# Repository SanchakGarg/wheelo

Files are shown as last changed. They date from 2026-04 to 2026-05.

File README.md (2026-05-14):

# Wheelo: Scissored CMG Balancing Robot

Wheelo is an open-source, single-axis balancing robot that uses a **Scissored Control Moment Gyroscope (CMG)** system for stabilization. Unlike traditional balancing robots that use wheel acceleration, Wheelo stays upright by harnessing gyroscopic precession torque.

## Videos

| Demo | Working Principle |
|---|---|
| Wheelo Demo (https://www.youtube.com/watch?v=aaRE76FrkvM) | Wheelo Working (https://www.youtube.com/watch?v=aowIbTuXIWc) |

## Key Features

- **Scissored CMG Design:** Two counter-rotating flywheels geared together to provide pure torque and cancel parasitic yaw/roll.
- **XIAO ESP32-C3 Core:** Compact, powerful microcontroller with WiFi/OTA capabilities.
- **High-Speed Actuation:** ST3215 1 Mbps Serial Bus Servo for precise gimbal control.
- **Advanced Filtering:** Mahony filter with Median and Low-Pass stages for stable orientation sensing.
- **Web Dashboard:** Real-time PID tuning, telemetry, and calibration via a built-in web server.
- **OTA Updates:** Flash new firmware over WiFi — no USB cable needed after first flash.

## Repository Structure

```
Wheelo/
├── firmware/main/          # PlatformIO ESP32-C3 project
│   ├── platformio.ini      # Build environments (usb + ota)
│   └── src/
│       ├── config.h        # All pin assignments and tunable constants
│       ├── main.cpp        # Entry point — wires up modules, runs 10 ms PID loop
│       ├── BalancePID.cpp/h     # XRobots-V2 style angle PID with setpoint accumulator
│       ├── MPUSensor.cpp/h     # MPU6050/6500 driver + Mahony filter
│       ├── ServoController.cpp/h  # ST3215 half-duplex UART servo
│       ├── ESCController.cpp/h # BLDC ESC PWM driver (capped at 30%)
│       └── WebUI.cpp/h         # HTTP server — dashboard, PID tuning, telemetry
├── hardware/
│   └── Gyroscope Assembly.3mf  # 3D print files (Bambu/PrusaSlicer)
├── tools/
│   ├── sim_filter.py       # Off-robot Mahony filter simulation against recorded data
│   └── telemetry.py        # Real-time WiFi telemetry logger
└── docs/
    └── sim_filter_results.png  # Filter validation output
```

## Hardware

### Components

| Role | Part |
|---|---|
| MCU | Seeed Studio XIAO ESP32-C3 |
| IMU | MPU6050 / MPU6500 |
| Gimbal Servo | Waveshare ST3215 (Serial Bus Servo, 1 Mbps) |
| Flywheel Motor | BLDC Motor + ESC (2S–3S LiPo) |

### Pin Map

| Signal | GPIO | Board Label |
|---|---|---|
| ESC PWM | 10 | D10 |
| Servo TX | 20 | D7 |
| Servo RX | 21 | D6 |
| MPU SDA | 6 | D4 |
| MPU SCL | 7 | D5 |

### CAD

The mechanical design is available on Onshape: **[Wheelo CAD](https://cad.onshape.com/documents/1c7d4ff26d1dc69175c3ae98/w/5cd2b66e5aeb4751e0f29f10/e/76622d04818cc6738350398c)**

## Firmware Architecture

The firmware is split into six modules, each a self-contained C++ class:

| Module | File | Responsibility |
|---|---|---|
| **BalancePID** | `BalancePID.cpp` | XRobots-V2 direct-position PID. Outputs gimbal position commands. Includes setpoint accumulator to absorb chassis lean bias and prevent gimbal saturation. |
| **MPUSensor** | `MPUSensor.cpp` | Reads MPU6050/6500 over I2C. Applies a Mahony complementary filter plus median and low-pass stages. Exposes `pitch` and `gyroY` in degrees. |
| **ServoController** | `ServoController.cpp` | Drives the ST3215 over half-duplex UART at 1 Mbps. Reads back live gimbal position every 50 ms for closed-loop velocity computation. |
| **ESCController** | `ESCController.cpp` | Generates standard 1000–2000 µs PWM for the BLDC ESC. Throttle is capped at 30% for safety. |
| **WebUI** | `WebUI.cpp` | Serves a single-page dashboard on port 80. Endpoints for PID gains, servo manual control, IMU calibration, balance start/stop, and live telemetry. |
| **main** | `main.cpp` | Wires modules together, connects to WiFi, starts OTA, and runs a 10 ms PID tick in `loop()`. |

### PID Loop

The balance loop runs at **100 Hz** (every 10 ms). Each tick:
1. `mpu.read()` — fetches and filters a new IMU sample.
2. `pid.compute()` — runs the PID, moves the gimbal via `servo`.
3. `servo.readPos()` — runs at 50 ms cadence, keeps the position feedback fresh.

### Setpoint Accumulator

The setpoint accumulator (`accumEnabled`) slowly drifts the balance target toward the chassis's natural lean angle. This prevents the gimbal from parking at the edge of its travel and saturating on any second disturbance.

## Firmware Setup

### Prerequisites

- [PlatformIO Core](https://platformio.org/) (CLI or VS Code extension)
- Python 3.x (for `tools/`)

### Configuration

Edit `firmware/main/src/config.h` before building:

```cpp
#define WIFI_SSID     "YourNetwork"
#define WIFI_PASS     "YourPassword"
#define OTA_PASSWORD  "wheelo123"   // change for production
```

### Build & Flash

**First flash (USB):**
```bash
cd firmware/main
pio run -e usb -t upload
```

**Subsequent flashes (OTA — robot must be on WiFi):**
```bash
pio run -e ota -t upload
```

Serial monitor at 115 200 baud:
```bash
pio device monitor
```

## Web Dashboard

Once connected to WiFi, the robot advertises itself as `wheelo.local`. Open `http://wheelo.local` in a browser.

Available controls:
- **PID gains** (Kp / Ki / Kd / Trim) — live update with save to NVS
- **Setpoint Accumulator** toggle
- **Servo manual position** control
- **IMU calibration** (zero gyro bias, noise floor measurement)
- **Balance start / stop**
- **Live telemetry** (angle, gimbal position, PID output)

## Tools

| Script | Usage |
|---|---|
| `tools/sim_filter.py` | Replay recorded IMU CSV through the Mahony filter off-robot to validate tuning. |
| `tools/telemetry.py` | Connect over WiFi and stream live telemetry to a CSV for post-analysis. |

## License

This project is open-source under the MIT License. Feel free to build, modify, and share!

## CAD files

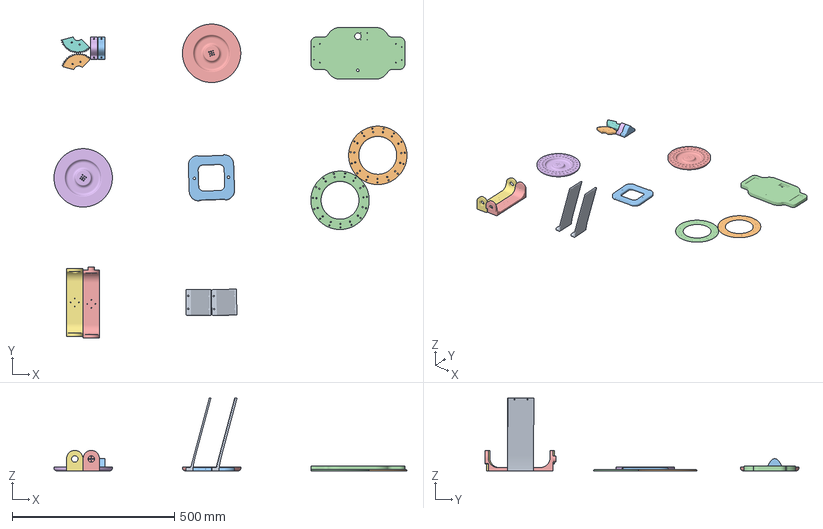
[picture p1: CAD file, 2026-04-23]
hardware/Gyroscope Assembly.3mf
1088.4 x 967.5 x 224.0 mm
Gyro - Support x 2
FlyWheel - cover x 2
Balance - Point x 2
Fly Wheel Stator - Mount x 2
Spur Gear x 2
Gyro - Top Joint
Gyro - Base
Fly Wheel - Base x 2

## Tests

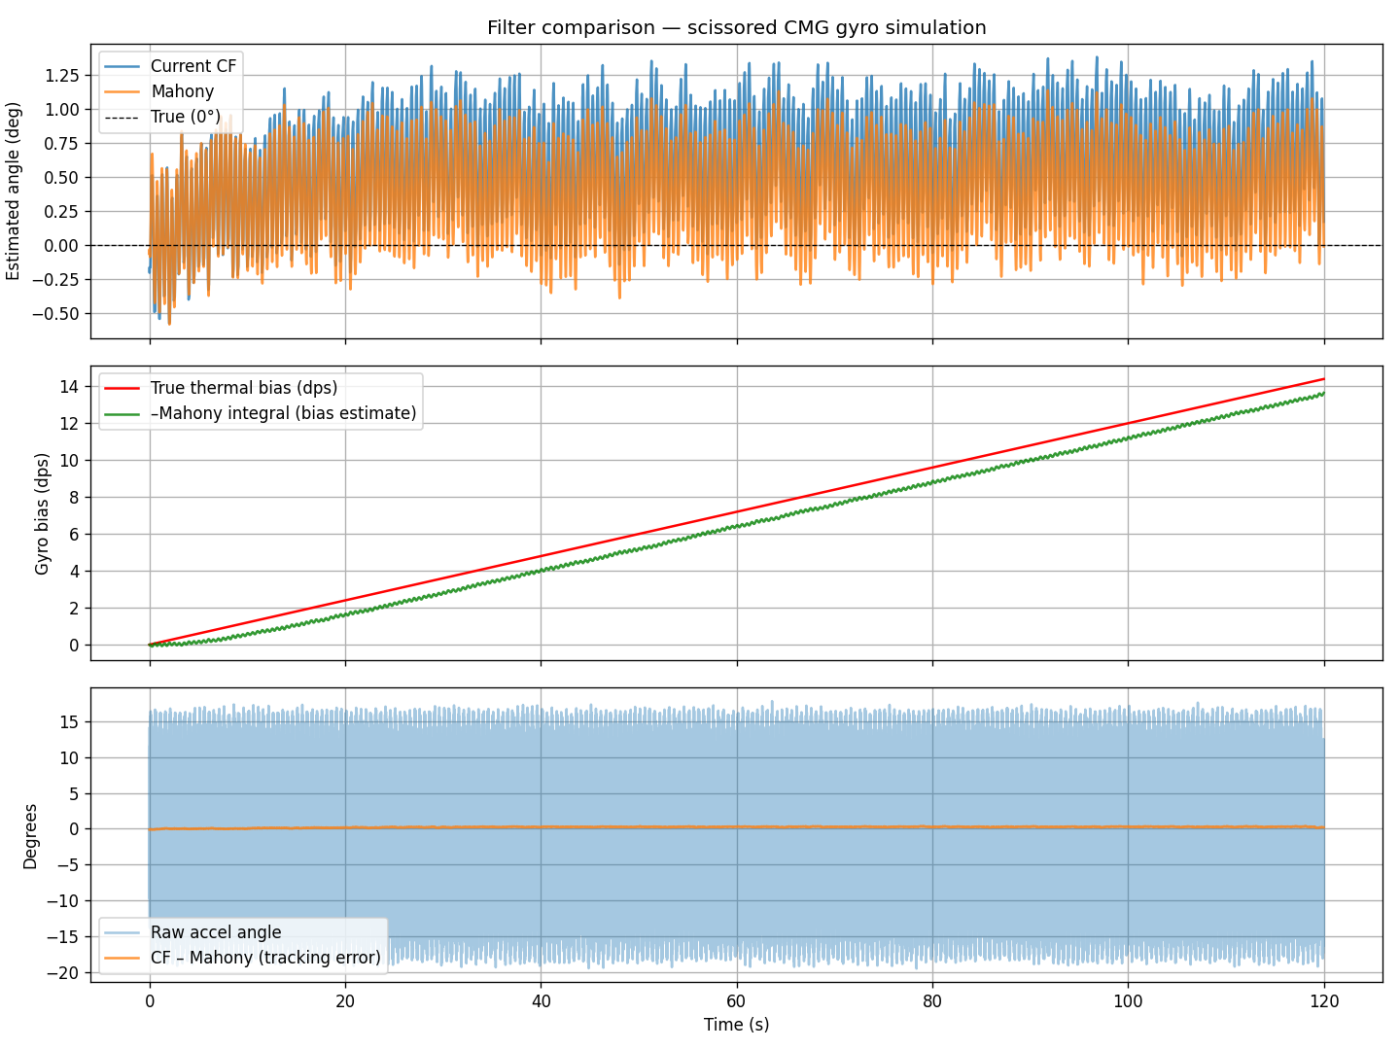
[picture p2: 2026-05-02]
docs/sim_filter_results.png

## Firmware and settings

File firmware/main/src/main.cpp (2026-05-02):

#include <Arduino.h>
#include <WiFi.h>
#include <WebServer.h>
#include <Preferences.h>
#include <ArduinoOTA.h>
#include "config.h"
#include "ESCController.h"
#include "ServoController.h"
#include "MPUSensor.h"
#include "BalancePID.h"
#include "WebUI.h"

Preferences     prefs;
WebServer       server(80);
ESCController   esc(PIN_ESC, ESC_MIN_US, ESC_MAX_US, ESC_MAX_PCT);
ServoController servo(SERVO_ID, BAUD_SERVO, PIN_SRV_RX, PIN_SRV_TX, SERVO_DEF, SERVO_SWING);
MPUSensor       mpu(MPU_ADDR, PIN_MPU_SDA, PIN_MPU_SCL);
BalancePID      pid(servo, mpu);
WebUI           ui(server, servo, esc, mpu, pid, prefs);

void setup() {
    Serial.begin(115200);
    delay(200);

    esc.begin();
    Serial.println("ESC armed at 0%");

    servo.begin(prefs);

    mpu.begin(prefs);
    pid.loadGains(prefs);

    WiFi.mode(WIFI_STA);
    WiFi.setSleep(false);
    WiFi.begin(WIFI_SSID, WIFI_PASS);
    Serial.print("WiFi");
    unsigned long t0 = millis();
    while (WiFi.status() != WL_CONNECTED && millis() - t0 < 30000) {
        delay(300);
        Serial.print('.');
        esc.setThrottle(0);
    }
    if (WiFi.status() == WL_CONNECTED)
        Serial.printf("\nIP: %s\n", WiFi.localIP().toString().c_str());
    else
        Serial.println("\nWiFi failed.");

    ui.begin();
    Serial.println("HTTP server started.");

    // OTA
    ArduinoOTA.setHostname(OTA_HOSTNAME);
    ArduinoOTA.setPassword(OTA_PASSWORD);
    ArduinoOTA.onStart([](){ Serial.println("OTA start"); });
    ArduinoOTA.onEnd([](){ Serial.println("\nOTA done"); });
    ArduinoOTA.onProgress([](unsigned int prog, unsigned int total){
        Serial.printf("OTA: %u%%\r", prog * 100 / total);
    });
    ArduinoOTA.onError([](ota_error_t err){
        Serial.printf("OTA error[%u]\n", err);
    });
    ArduinoOTA.begin();
    Serial.printf("OTA ready — hostname: %s\n", OTA_HOSTNAME);
}

void loop() {
    ArduinoOTA.handle();
    ui.handle();

    static uint32_t lastLoop = 0;
    static uint32_t lastReadPos = 0;
    uint32_t now = millis();

    // 10ms PID tick
    if (now - lastLoop >= 10) {
        if (mpu.read()) { pid.compute(); }
        lastLoop = now;
    }

    // 50ms servo position read. Runs during balancing too — compute() uses
    // currentPos as its velocity base, so it must stay fresh. readPos has a
    // 3ms timeout, so at worst one in five 10ms PID ticks is 3ms late.
    if (now - lastReadPos >= 50) {
        servo.readPos();
        lastReadPos = now;
    }
}

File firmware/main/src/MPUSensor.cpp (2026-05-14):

#include "MPUSensor.h"
#include "config.h"
#include <math.h>

MPUSensor::MPUSensor(uint8_t addr, int sda, int scl)
    : _addr(addr), _sda(sda), _scl(scl) {}

// 2nd-order Butterworth Low-Pass Biquad. 
// Sharp -40dB/decade roll-off to kill scissored-CMG vibration.
static float biquadLP(float x, float cutoffHz, float dt, MPUSensor::BiquadState &s) {
    float wc = 2.0f * 3.14159265f * cutoffHz;
    float k = wc * dt / 2.0f;
    float k2 = k * k;
    float sqrt2 = 1.41421356f;
    float norm = 1.0f / (1.0f + sqrt2 * k + k2);
    
    float b0 = k2 * norm;
    float b1 = 2.0f * b0;
    float b2 = b0;
    float a1 = 2.0f * (k2 - 1.0f) * norm;
    float a2 = (1.0f - sqrt2 * k + k2) * norm;

    float y = b0*x + b1*s.x1 + b2*s.x2 - a1*s.y1 - a2*s.y2;
    s.x2 = s.x1; s.x1 = x;
    s.y2 = s.y1; s.y1 = y;
    return y;
}

static float lowPass(float prev, float x, float cutoffHz, float dt) {
    const float rc = 1.0f / (2.0f * 3.1415926535f * cutoffHz);
    const float alpha = constrain(dt / (rc + dt), 0.0f, 1.0f);
    return prev + alpha * (x - prev);
}

// 5-element sorting network → median. Branch-only, ~9 compares, no allocs.
// Median rejects the impulse spikes BLDC commutation injects into the gyro
// without introducing the phase lag of an equivalent low-pass filter.
static inline void cas(float &a, float &b) {
    if (a > b) { float t = a; a = b; b = t; }
}
static float median5(float v0, float v1, float v2, float v3, float v4) {
    float a = v0, b = v1, c = v2, d = v3, e = v4;
    cas(a, b); cas(d, e);
    cas(c, e); cas(c, d);
    cas(a, d); cas(a, c);
    cas(b, e); cas(b, d);
    cas(b, c);
    return c;
}

bool MPUSensor::writeReg(uint8_t reg, uint8_t value) {
    Wire.beginTransmission(_addr);
    Wire.write(reg);
    Wire.write(value);
    return Wire.endTransmission() == 0;
}

bool MPUSensor::readReg(uint8_t reg, uint8_t &value) {
    Wire.beginTransmission(_addr);
    Wire.write(reg);
    if (Wire.endTransmission(false) != 0) return false;
    if (Wire.requestFrom(_addr, (uint8_t)1, (uint8_t)true) != 1) return false;
    int v = Wire.read();
    if (v < 0) return false;
    value = (uint8_t)v;
    return true;
}

bool MPUSensor::rawRead(int16_t out[7]) {
    Wire.beginTransmission(_addr);
    Wire.write(REG_ACCEL_XOUT);
    if (Wire.endTransmission(false) != 0) return false;

    uint8_t n = Wire.requestFrom(_addr, (uint8_t)14, (uint8_t)true);
    if (n != 14) return false;

    for (int i = 0; i < 7; i++) {
        int hi = Wire.read();
        int lo = Wire.read();
        if (hi < 0 || lo < 0) return false;
        out[i] = (int16_t)((hi << 8) | lo);
    }

    if (MPU_UPSIDE_DOWN) {
        // Chip flipped 180° about its X axis. Accel Y/Z and gyro Y/Z
        // invert; accel X (out[0]), temp (out[3]), and gyro X (out[4])
        // stay the same because the rotation axis IS X.
        out[1] = (int16_t)-out[1];
        out[2] = (int16_t)-out[2];
        out[5] = (int16_t)-out[5];
        out[6] = (int16_t)-out[6];
    }
    return true;
}

void MPUSensor::begin(Preferences& prefs) {
    Wire.begin(_sda, _scl);
    Wire.setClock(100000);
    delay(250);

    Serial.printf("I2C SDA=GPIO%d SCL=GPIO%d\n", _sda, _scl);
    int found = 0;
    for (uint8_t a = 1; a < 127; a++) {
        Wire.beginTransmission(a);
        if (Wire.endTransmission() == 0) { Serial.printf("  device @ 0x%02X\n", a); found++; }
    }
    if (!found) { Serial.println("  no I2C devices"); ok = false; return; }

    Wire.beginTransmission(_addr);
    if (Wire.endTransmission() != 0) { Serial.println("MPU6050: no ACK"); ok = false; return; }

    uint8_t who = 0;
    if (readReg(REG_WHO_AM_I, who)) {
        Serial.printf("MPU6050 WHO_AM_I=0x%02X\n", who);
    } else {
        Serial.println("MPU6050 WHO_AM_I read failed");
    }

    if (!writeReg(REG_PWR_MGMT_1, 0x01)) { ok = false; return; }
    delay(10);
    if (!writeReg(REG_CONFIG, MPU_DLPF_CFG)) { ok = false; return; }
    if (!writeReg(REG_SMPLRT_DIV, MPU_SMPLRT_DIV)) { ok = false; return; }
    if (!writeReg(REG_ACCEL_CFG, 0x00)) { ok = false; return; } // +/-2g
    if (!writeReg(REG_GYRO_CFG, 0x00)) { ok = false; return; }  // +/-250 dps
    ok = true;

    prefs.begin(NVS_NS, true);
    _biasAx        = prefs.getFloat("b_ax",      0);
    _biasAy        = prefs.getFloat("b_ay",      0);
    _biasAz        = prefs.getFloat("b_az",      0);
    _biasGx        = prefs.getFloat("b_gx",      0);
    _biasGy        = prefs.getFloat("b_gy",      0);
    _biasGz        = prefs.getFloat("b_gz",      0);
    angleOffset    = prefs.getFloat("ang_off",   0);
    gyroNoiseFloor    = prefs.getFloat("gyro_noise",     1.0f);
    accelInnovDeadband = prefs.getFloat("accel_innov_db", 1.5f);
    bool hasBias   = prefs.getBool("bias_ok", false);
    prefs.end();

    if (!hasBias) {
        Serial.println("No bias — auto-cal (keep still ~2 s)…");
        calibrate(prefs, 200);
    } else {
        Serial.println("MPU6050 ready");
    }
}

void MPUSensor::resetFilters() {
    _eAx = _eAy = _eAz = _eGx = 0.0f;
    _cfAngle = 0.0f;
    _mahonyInt = 0.0f;
    _lastUs = 0;
    _cfInited = false;
    _medIdx = 0;
    _medCount = 0;
    for (size_t i = 0; i < MEDIAN_N; i++) {
        _gxMed[i] = _axMed[i] = _ayMed[i] = _azMed[i] = 0.0f;
    }
    _accelNormFilt = 1.0f;
    rateDps = 0.0f;
    accelAngle = 0.0f;
    accelNormG = 1.0f;
}
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

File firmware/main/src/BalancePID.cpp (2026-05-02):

#include "BalancePID.h"
#include "config.h"

BalancePID::BalancePID(ServoController& servo, MPUSensor& mpu)
    : _servo(servo), _mpu(mpu) {}

void BalancePID::loadGains(Preferences& prefs) {
    prefs.begin(NVS_NS, true);
    kp           = prefs.getFloat("pid_kp", 1.8f);
    ki           = prefs.getFloat("pid_ki", 0.0f);
    kd           = prefs.getFloat("pid_kd", 0.09f);
    trim         = prefs.getFloat("pid_tr", 0.0f);
    accumEnabled = prefs.getBool("pid_acc_en", false);
    prefs.end();
}

void BalancePID::saveGains(Preferences& prefs) {
    prefs.begin(NVS_NS, false);
    prefs.putFloat("pid_kp", kp);
    prefs.putFloat("pid_ki", ki);
    prefs.putFloat("pid_kd", kd);
    prefs.putFloat("pid_tr", trim);
    prefs.putBool("pid_acc_en", accumEnabled);
    prefs.end();
}

void BalancePID::start() {
    _outputSum    = 0.0f;
    _prevOutput   = 0.0f;
    setpointAccum = 0.0f;
    output        = 0.0f;
    running       = true;
}

void BalancePID::stop() {
    running       = false;
    _outputSum    = 0.0f;
    _prevOutput   = 0.0f;
    setpointAccum = 0.0f;
    output        = 0.0f;
    _servo.moveTo(_servo.defaultPos);
}

void BalancePID::compute() {
    if (!running) return;

    float angle = _mpu.angle;

    if (fabsf(angle) > SAFETY_DEG) {
        Serial.printf("[PID] Safety cut at %.1f deg\n", angle);
        stop();
        return;
    }

    if (accumEnabled) {
        // Drift setpoint toward centre to allow gimbal re-centering.
        setpointAccum += _prevOutput / SETPOINT_ACCUM_DIV;
        setpointAccum  = constrain(setpointAccum, -SETPOINT_ACCUM_LIMIT, SETPOINT_ACCUM_LIMIT);
    } else {
        setpointAccum = 0.0f;
    }

    float setpoint = setpointAccum + trim;
    float error    = setpoint - angle;
    float rate     = _mpu.rateDps;

    // PID_v1-equivalent integral with derivative damping from filtered gyro rate.
    const float ki_int = ki * SAMPLE_TIME_S;
    const float iError = fabsf(error) > ANGLE_DEADBAND_DEG ? error : 0.0f;
    const float dRate  = fabsf(rate)  > _mpu.gyroNoiseFloor ? rate  : 0.0f;

    _outputSum += ki_int * iError;
    _outputSum  = constrain(_outputSum, -OUTPUT_LIMIT, OUTPUT_LIMIT);

    float desired = kp * error + _outputSum - kd * dRate;
    if (fabsf(error) < ANGLE_DEADBAND_DEG && fabsf(rate) < RATE_DEADBAND_DPS) {
        desired = 0.0f;
        _outputSum *= 0.98f;
    }

    desired = constrain(desired, -OUTPUT_LIMIT, OUTPUT_LIMIT);
    
    // Output Gating / Deadzone:
    // Only update the actual 'output' (which drives the servo) if the 'desired' 
    // change is larger than our noise deadzone. This stops the robot from 
    // "buzzing" when it's just sitting there vibrating.
    if (fabsf(desired - _prevOutput) > SERVO_DEADZONE_DEG) {
        output = _prevOutput + constrain(desired - _prevOutput,
                                         -MAX_OUTPUT_STEP,
                                          MAX_OUTPUT_STEP);
        _prevOutput = output;
    } else {
        // Change is too small (likely noise) — stay put.
        output = _prevOutput;
    }

    // Velocity control: move servo BY `output`° from its current actual position.
    // CMG torque ∝ gimbal rate, so each cycle we command a step from wherever the
    // servo actually is (currentPos, read every 50ms) — not from a fixed defaultPos.
    // This means a stalled or slipped servo gets corrected on the next position read.
    _servo.moveTo(_servo.currentPos + SERVO_DIR * (int)(output / 0.088f));
}

void BalancePID::setGains(float newKp, float newKi, float newKd, float newTrim,
                          Preferences& prefs) {
    kp = newKp; ki = newKi; kd = newKd; trim = newTrim;
    _outputSum    = 0.0f;
    _prevOutput   = 0.0f;
    setpointAccum = 0.0f;
    _servo.moveTo(_servo.defaultPos);
    saveGains(prefs);
}

void BalancePID::setAccumEnabled(bool enabled, Preferences& prefs) {
    accumEnabled  = enabled;
    setpointAccum = 0.0f;
    _outputSum    = 0.0f;
    _prevOutput   = 0.0f;
    saveGains(prefs);
}

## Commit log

2026-04-23 Initial commit — Wheelo XIAO ESP32-C3 firmware
    BLDC ESC control, ST3215 servo CMG gimbal, MPU6050 complementary
    filter at 500 Hz, web UI with auto-balance PID (direct position mode).
    [Gyroscope Assembly.3mf]
2026-04-23 Switch PID to gimbal velocity mode (SetpointAccum)
    Instead of commanding the servo directly to a fixed position, pidOutput
    now feeds into a gimbalAccum integrator each loop. The accumulator is
    clamped to the swing limit so the gimbal keeps cycling and generates
    continuous CMG torque rather than parking at an offset and going silent.
    GIMBAL_ACCUM_RATE=800 controls how aggressively the output ramps — tune
    this value once Kp/Kd are stable.
    [main.cpp]
2026-04-24 Refactor into OOP multi-file structure
    Split monolithic main.cpp into focused classes:
    config.h — all pins and constants
    ESCController — PWM ESC wrapper
    ServoController — ST3215 half-duplex UART
    MPUSensor — MPU6050, EMA, complementary filter, calibration
    BalancePID — PID with gimbal velocity accumulator
    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
2026-04-24 Add OTA, PID range table in UI, recommended defaults
    - ArduinoOTA on hostname 'wheelo', password 'wheelo123'
    - platformio.ini split into [env:usb] and [env:ota]
    - OTA upload: pio run -e ota -t upload (robot on WiFi)
    - PID range reference table added to balance panel
    - Default inputs updated to recommended: Kp=0.35 Kd=0.10 Ki=0
2026-04-24 Reset gimbal to default pos on every PID gain change
    [BalancePID.cpp]
2026-04-24 Fix PID: match XRobots direct-position algorithm, remove normalization
    Previous gimbalAccum approach caused double integration (Ki integrated
    once by PID, again by accumulator) making gains impossible to tune.
    Now matches XRobots ControlMomentGyros V3:
    - Output is direct servo deflection in degrees (not integrated velocity)
    - SetpointAccum shifts PID target slowly for gimbal re-centering
    - No 0-1 normalization — gains are physical values (Kp=3.5 Kd=0.10)
    - Web UI updated with new ranges and step sizes
    [BalancePID.cpp, BalancePID.h]
2026-04-24 Fix UI: sync gimbalAccum → setpointAccum after PID refactor
2026-04-25 Switch balance loop to XRobots V2 style angle PID and add telemetry logger
2026-04-25 sensor stabilisation
2026-04-25 Filter MPU gyro noise before balance PID
    [BalancePID.cpp, BalancePID.h, MPUSensor.cpp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]
2026-04-30 Replace CF+deadband with Mahony filter; add gyro drift simulation
    The previous innovation deadband approach created a blind spot where
    slow thermal gyro drift accumulated uncorrected, causing 8 deg drift.
    Hard-deadband width from noise cal with flywheel running made this worse.
    Mahony complementary filter (Kp=2.0, Ki=0.30):
    - No hard innovation deadband — BLDC vibration rejected by 4 Hz accel
    LP filter and the 0.32 Hz Mahony crossover frequency instead
    - Integral term (_mahonyInt) accumulates online bias correction that
    converges to -(thermal_drift_dps), capping ramp-drift error at
    drift_rate/Ki = 0.12/0.30 = 0.4 deg under worst-case heating
    - Python simulation (sim_filter.py) confi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
    [MPUSensor.cpp, MPUSensor.h]
2026-05-02 Restructure repository for open-source release
    Organized files into firmware, hardware, tools, and docs directories. Added README.md and cleaned up build artifacts and logs.
    [Gyroscope Assembly.3mf]
2026-05-02 Fix: Restore PlatformIO 'src' directory structure
    [BalancePID.cpp, BalancePID.h, MPUSensor.cpp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]
2026-05-02 Remove servo_test directory
2026-05-02 Fix: compilation errors and C++17 inheritance
    [BalancePID.cpp, BalancePID.h, MPUSensor.cpp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]
2026-05-02 Fix: final cleanup of MPU header and build flags
    [MPUSensor.h]
2026-05-14 Improve README with videos, architecture docs
    - Replace sim_filter_results.png with clickable YouTube thumbnails
    - Add hardware pin map, firmware architecture table, PID loop description
    - Add web dashboard and tools reference sections
    [MPUSensor.cpp, MPUSensor.h]
2026-05-14 Add Onshape CAD link to README
